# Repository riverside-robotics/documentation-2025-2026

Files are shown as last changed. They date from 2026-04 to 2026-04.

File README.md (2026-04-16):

# Spinlayden 2.0 — Riverside Robotics Documentation

**Team Meltdown** | Riverside High School | AWT RoboBots 2025-2026

**Documentation Due:** April 18, 2026 (11:59 PM)
**Competition:** April 25, 2026

---

## Repository Structure

| File | Description |
|---|---|
| `main.md` | Main documentation file — all sections for the AWT submission |
| `meetingNotes.md` | Meeting minutes from September 2025 to April 2026 |
| `aboutStudents.md` | Team member biographies (submit yours here) |
| `todo.md` | Tracks what still needs to be done and what has been completed |
| `interviewPrep.md` | Interview preparation for the 15-minute judge interview |
| `designTeamRequest.md` | Checklist of items needed from the design/CAD team |
| `rubricCompliance.md` | Tracks how far we are with AWT rubric compliance |
| `Images/` | Folder for all photos, CAD renders, and diagrams |

---

## How to Contribute

### Submitting Your Bio

Add your biography to `aboutStudents.md` — **do not** put it directly in `main.md`. Tom will move it into the main doc.

### Uploading Images

Upload images to the `Images/` folder and let Tom know which ones to use and where they should go in the doc.

### Helping with the Documentation

Check `todo.md` for outstanding tasks. When you complete one, mark it as done by wrapping the line with `~~` (strikethrough). See existing completed items in `todo.md` for examples.

### Submitting Design Content

If you are on the design or CAD team, check `designTeamRequest.md` for the specific items needed (CAD renders, engineering drawings, design descriptions). Send completed items to Tom or drop them in Google Classroom.

---

## Quick Links

- **Main Doc:** [main.md](main.md)
- **Meeting Notes:** [meetingNotes.md](meetingNotes.md)
- **TODO List:** [todo.md](todo.md)
- **Interview Prep:** [interviewPrep.md](interviewPrep.md)
- **Design Team Request:** [designTeamRequest.md](designTeamRequest.md)
- **Rubric Compliance:** [rubricCompliance.md](rubricCompliance.md)

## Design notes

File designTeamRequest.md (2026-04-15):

# Design Team — Content Needed for Documentation

**From:** Tom (Documentation)
**To:** Adam, Ayden, Jayden, Adam P., and the rest of the design team
**Deadline:** ASAP — documentation is due April 18 at 11:59 PM, competition is April 25

---

## What This Is

The **Design** section of our main documentation still has placeholder content. I need the design team to provide the following items so I can fill it in. Below is exactly what's needed, with examples from last year's Spinlayden doc and the Blue Streak of Death example doc for reference.

---

## Item 1: Previous Bot Write-Up

**What I need:** A short write-up about Spinlayden 1.0 (2025) similar to how last year's doc covered Mass & Acceleration.

**Format (follow this structure):**

> **Spinlayden 1.0 — 2025**
>
> [1-2 sentence description of the bot and what it taught us]
>
> [Photo/render of Spinlayden 1.0]
>
> **Strengths:**
> - [bullet points]
>
> **Weaknesses:**
> - [bullet points]

**What I already have (you can confirm, edit, or add to these):**

Strengths I've identified from the docs:
- Hexagonal full-body spinner concept worked
- Meltybrain drive system allowed spin + translate simultaneously
- Double-sided design — operates when flipped
- 6061 aluminum chassis was strong and lightweight
- A516 carbon steel blades held up to impact

Weaknesses I've identified:
- Weight reduction holes weakened the walls
- Components were too close to the outer walls
- Claw-style blades didn't puncture well
- No housing for the Raspberry Pi
- Python software had input lag
- Bluetooth controller dropped connection
- Counterweight system was overly complex

**What I still need from you:**
- [ ] A photo or CAD render of Spinlayden 1.0 (the old bot)
- [ ] Confirm or correct the strengths/weaknesses above
- [ ] A 1-2 sentence summary of what Spinlayden 1.0 taught us as a team

---

## Item 2: Design Section Introduction

**What I need:** A short paragraph (3-5 sentences) introducing the Design section. This goes at the very top, before Influences.

**It should cover:**
- What the design philosophy is for Spinlayden 2.0
- Why we chose to iterate on the existing design rather than start fresh
- A brief mention of the key improvements this year

**Example from last year's doc:**
> *"Spinlayden's design is driven by the goal of delivering maximum damage while maintaining agility and resilience. The 14" x 12" hexagonal chassis, crafted from 1/8" 6061 aluminum with vent-like cutouts, optimizes weight and heat dissipation..."*

**What I still need from you:**
- [ ] A short intro paragraph for the Design section (or bullet points and I'll write it up)

---

## Item 3: 2026 Design Description

**What I need:** Content for the `**2026 Design:**` line near the top of the doc (currently empty, line 39).

**It should be:** 1-3 sentences summarizing this year's design direction.

**Example:** "For 2026, Spinlayden has been redesigned from the ground up while keeping the proven hexagonal meltybrain full-body spinner concept. Key improvements include redesigned weight reduction, a dedicated Raspberry Pi housing, sharper spike-style blades, and a complete software rewrite in C#."

**What I still need from you:**
- [ ] Confirm the example above works, or write your own version

---

## Item 4: CAD Renders / Photos

**What I need:** Images for the documentation. The example doc (Blue Streak of Death) had multiple CAD views and photos throughout.

**Specifically needed:**
- [ ] CAD render of Spinlayden 2.0 — isometric/3D view (like last year's doc page 51)
- [ ] CAD render — top-down view showing blade layout
- [ ] CAD render — side view showing wall height and weight reduction
- [ ] Photo of the old Spinlayden 1.0 bot (for the Previous Bot section)
- [ ] Any in-progress build photos (assembly, waterjet cutting, CNC milling, 3D printing)
- [ ] Exploded view of the assembly if available in Fusion 360

---

## Item 5: Engineering Drawing Set

**What I need:** Dimensioned engineering drawings from Fusion 360.

**The example doc (pages 92-105) included drawings for:**
- Overall assembly with key dimensions
- Individual fabricated parts (chassis plates, walls, blades)
- Motor/component specs and mounting locations

**What I still need from you:**
- [ ] Export dimensioned drawings from Fusion 360 (PDF or image format)
- [ ] Include: overall dimensions, bolt hole patterns, weight reduction geometry, blade dimensions

---

## Summary Checklist

| # | Item | Who | Done? |
|---|---|-----|---|
| 1 | Previous Bot write-up (confirm strengths/weaknesses + photo) | Adam, Design team | [ ] |
| 2 | Design section intro paragraph | Adam, Design team | [ ] |
| 3 | 2026 Design description (1-3 sentences) | Adam, Design team | [ ] |
| 4 | CAD renders (isometric, top-down, side, exploded) | Ayden, Adam P., Jayden | [ ] |
| 5 | Photo of Spinlayden 1.0 | Anyone who has one | [ ] |
| 6 | In-progress build photos | Everyone | [ ] |
| 7 | Engineering drawings from Fusion 360 | CAD team | [ ] |

Please send completed items to Tom or drop them in the Google Classroom. Even partial info is helpful — I can write it up from bullet points.

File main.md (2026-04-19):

# Spinlayden 2.0

## Team Meltdown — Riverside Robotics

**Riverside High School** · 585 Riverside Dr, Painesville, OH 44077

**AWT Regional RoboBots Competition — 2025–2026 Season**

### Team Members

| | | |
|---|---|---|
| Adam Pakeltis | Alexander Holmes | Ayden Moore |
| Benjamin Mackey | Daniel George | Dustin Hance |
| Jason Kellhofer | Jayden Craig | Kasey Kurzinger |
| Kaydan Kerr | Lukas Dauksa | Mher Poghosyan |
| Robert Rateno | Richard Rowland | Sultan Kazeem |
| Tom Kramer | Vincent Riha | Xayden Minch |
| Yash Jain | | |

**Advisors:** Jack Carbone, Adam Carbone &nbsp;·&nbsp; **Industry Advisor:** J.T. Mackey (Monode Marking Products, Inc.)

**Sponsors:** Monode Marking Products, Inc. &nbsp;·&nbsp; Show Studio LLC &nbsp;·&nbsp; Arc Technology LLC

---

## Meet the Robotics Team

**Overview:** Since 2022, Riverside High School had been without a robotics team. Former Class of 2023 students, Adam and Jack Carbone, took the opportunity to establish one. In just four months, from January to April, not only was a team formed, but Riverside Robotics also learned to design and manufacture its first robot in years, Spinlayden. This year, the high school roster has grown to 19 students on Team Meltdown, with two additional JuniorBots middle-school teams also running under advisors Jack and Adam Carbone.

**2026 Design:** Spinlayden 2.0 is the team's second-generation 15-pound hexagonal meltybrain full-body spinner, built around a 6061 aluminum chassis with six 1/2" carbon steel hex bolts as impact weapons and driven by dual BaneBots P61 gearboxes at 645.6 RPM (≈26.9 mph tip speed, ~78 J per rotation). This season's redesign focuses on the failure points identified from Spinlayden 1.0 — reinforcing the chassis walls, redesigning the gearbox and bearing mounts for easier serviceability and better belt tension, and moving the meltybrain control software from Python to C# on a Raspberry Pi for tighter simultaneous-rotation-and-translation drive control.

---

## Table of Contents

- [About Riverside](#about-riverside)
- [Our Partners](#our-partners)
- [Team Biographies](#team-biographies)
- [Mentor / Advisor Biographies](#mentor--advisor-biographies)
- [Acknowledgements](#acknowledgements)
- [Design](#design)
  - [Influences](#influences)
  - [Key Stats of the Bot](#key-stats-of-the-bot)
  - [What Was Changed from the Previous Design](#what-was-changed-from-the-previous-design)
- [Project Overview](#project-overview)
  - [General Information](#general-information)
  - [Sponsors](#sponsors)
  - [Advisors](#advisors)
  - [Manufacturing](#manufacturing)
  - [Bot Description](#bot-description)
  - [Objective](#objective)
  - [Team Members](#team-members)
  - [Deliverables](#deliverables)
  - [Key Milestones](#key-milestones)
  - [Constraints / Risks / Dependables](#constraints--risks--dependables)
- [Team Meltdown - Tasks Distribution](#team-meltdown---tasks-distribution)
  - [Project Assignments](#project-assignments)
- [Team Procedures](#team-procedures)
  - [Material Management](#material-management)
  - [Our Component Philosophy](#our-component-philosophy)
  - [Fabrication](#fabrication)
  - [Inventory](#inventory)
- [Design Process](#design-process)
  - [Research](#research)
  - [Strategy](#strategy)
  - [Analysis and Conceptualization](#analysis-and-conceptualization)
  - [Design Motivation](#design-motivation)
  - [Research Methods](#research-methods)
  - [Risk Analysis](#risk-analysis)
  - [Structural Analysis](#structural-analysis)
  - [Weapon System Details](#weapon-system-details)
  - [Drive System Details](#drive-system-details)
  - [Power System Details](#power-system-details)
  - [Wiring Schematic](#wiring-schematic)
  - [Testing Results](#testing-results)
- [That's a Wrap!](#thats-a-wrap)

---

## About Riverside

Riverside High School is a public high school located in Painesville, Ohio, serving the communities of Painesville Township, Concord, Leroy, and Grand River in Lake County. Part of Riverside Local Schools, the district holds true to its mission of providing A Pathway to Excellence by immersing students in educational opportunities that prepare them for success in college, careers, and beyond. Riverside strives to develop well-rounded individuals who are proactive in their communities and equipped with the skills necessary to thrive in a rapidly evolving world.

Connecting with this commitment to excellence, Riverside Robotics encourages hands-on learning, creative problem-solving, and independent thinking—qualities that are essential both in the arena and in life. Advised by Jack Carbone and Adam Carbone, both Class of 2023 alumni who returned to volunteer their time, Riverside Robotics aims to uphold the school's mission through the range of experiences in which students participate.

Riverside Robotics has a rich history dating back to the 2010s, competing in the AWT RoboBots program at Lakeland Community College—Ohio's largest regional combat robotics competition and a National Robotics League sanctioned event. In 2021, the team earned third place with Pfizer and Moderna, a pair of weaponless wedge bots designed around a strategy of control, domination, and superior torque. The following year, the team fielded Mass and Acceleration, a non-uniform dual-bot entry featuring both spinner and wedge designs, demonstrating the program's continued commitment to innovation and experimentation.

Following a brief hiatus, Riverside Robotics was revived in 2025 when alumni advisors Jack and Adam Carbone returned to reestablish the program. In just four months, from January to April, not only was a team of eight students formed, but Riverside Robotics also learned to design and manufacture its first robot in years: Spinlayden, a 15-pound meltybrain full-body spinner. Although competition results were modest, the inaugural revival season proved to be an overwhelming success—a year defined by excitement, growth, and invaluable learning experiences for every member of the new team.

At Riverside, the robotics program has achieved significant success beyond the arena. Alumni of the program have gone on to pursue degrees in mechanical engineering, software engineering, and other engineering disciplines at colleges and universities. Through robotics, students gain exposure to real-world manufacturing skills, CAD design, electronics, and the iterative process of engineering—experiences that have shaped their academic and professional futures.

The 2025-2026 season marks a historic expansion for Riverside Robotics. The high school competition team, Team Meltdown, has grown to 19 students fielding Spinlayden 2.0, an evolved iteration of the meltybrain spinner. Alongside the high school team, the JuniorBots program was revived from scratch this year, with two middle school teams—Team Pickle Pirates competing with The Pickler, a horizontal spinner, and Team Tornadoes bringing The Tempest to the arena. Each JuniorBots team boasts 15 to 20 students, a testament to the growing enthusiasm for robotics throughout the district.

The goal of Riverside Robotics is not only to compete at the highest level, but also to spread the joy of engineering and instill valuable skills applicable in the real world. Through teamwork and collaboration, students learn how to support each other, solve complex problems under pressure, and transform ideas into reality. This aligns closely with Riverside's mission of providing a pathway to excellence, and embodies a spirit of innovation, leadership, and perseverance.

---

## Our Partners

Riverside Robotics is proud to partner with local businesses and organizations that share our commitment to inspiring the next generation of engineers and innovators. Their generous support makes our program possible.

### Monode Marking Products, Inc.

Monode Marking Products, Inc. is an American manufacturer specializing in permanent part-marking and traceability solutions for industrial applications. As a third-generation, family-owned business celebrating 75 years in the marking industry, Monode has built its reputation on delivering practical, reliable solutions that perform in real-world environments.

Headquartered in Mentor, Ohio, Monode maintains a strong focus on North America while serving customers worldwide across industries including the Department of Defense, aerospace, automotive, medical, and food and drug sectors. The company provides a full range of marking technologies, including laser, dot peen, electro-chemical etching, steel stamp, and high precision die systems, along with integrated machine vision solutions.

What sets Monode apart is its focus on the complete system—not just the marking device. By combining marking hardware, proprietary software, and system integration with existing customer workflows, Monode delivers solutions that are reliable, scalable, and built for long-term use. Their team works closely with customers to design, implement, and support turnkey systems that meet production demands while ensuring compliance with requirements such as DoD Item Unique Identification (IUID).

Beyond equipment, Monode provides consulting, system design, installation, training, and ongoing support to ensure customers achieve consistent performance and long-term value. This practical, full-system approach has made Monode a trusted partner for organizations that depend on accurate, repeatable, and fully traceable marking solutions.

If you would like to learn more about Monode Marking Products, we encourage you to visit: https://www.monode.com/

### Arc Technology LLC

Arc Technology LLC is an electronics and engineering company founded in 2025 by Riverside Robotics advisor Adam Carbone. Based in Cleveland, Ohio, Arc Technology designs, develops, and delivers innovative products across engineering, electronics, and emerging technologies. Their flagship product, the FPV Sim Link, is a patent-pending device that converts HDMI to 5.8GHz RF for FPV drone simulator training. Arc Technology provides financial support to help sustain and grow the robotics program.

### Show Studio LLC

Show Studio LLC is a software company founded in 2025 by Riverside Robotics advisor Jack Carbone. Inspired by Riverside High School's own Riverside Regiment marching band, Show Studio develops marching band drill design software delivered as a Software-as-a-Service platform. The software features 3D visualization and coordinate generation tools to help band directors and designers bring their creative visions to life. Currently in beta, Show Studio provides Riverside Robotics with funding, 3D printers, portable CNC mills, and other materials essential for robot fabrication.

Through the combined support of our partners, Riverside Robotics is able to offer students access to professional-grade resources, real-world manufacturing experience, and mentorship that prepares them for careers in engineering and technology.

---

## Team Biographies

**Adam Pakeltis:** This hardworking senior is thrilled to join Team Meltdown for his very first year. Alongside robotics, Adam has played football and is an active member of the National Honor Society. Outside of the cage, this first-time competitor stays incredibly busy. He volunteers for both NHS and the Lake Metroparks, works weekends at Hellriegel's Inn, lifts weights, fishes, and enjoys working outside. When he isn't building plastic model kits or designing projects in Fusion 360, he loves hanging out with his girlfriend and watching "Deal or No Deal" with his family. This well-rounded student is more than ready to bring his diverse skills to the team and experience his first competition.

**Alexander Holmes:** Returning for his second year, this sharp junior brings a strategic mindset to Team Meltdown and leads the team's marketing operations. Along with robotics, he is actively involved in Accounting and Model UN. Outside of school, he enjoys reading, following Formula 1, and competing in fencing. With a full season of experience behind him, Alexander is well positioned to represent the team at competition.

**Ayden Moore:** This returning junior is back and ready to conquer the cage for his second competition. As the team's all-around helper, Ayden is actively involved in Robotics, Esports, and NTHS. Outside of school, he enjoys programming, exercising, watching TV, and playing video games. This versatile competitor is eager to take the wheel to drive a bot and watch it win.

**Benjamin Mackey:** This enthusiastic eighth grader is thrilled to step into the cage for his very first year. At 14 years old, Ben brings a positive attitude and a strong love for math to the team. Always happy to help and ready for a challenge, this cheerful rookie is excited to calculate the team's path to victory and gain valuable experience in his first competition.

**Daniel George:** This talented junior is stepping into the cage for his very first time. Daniel brings his skills to both the mechanical and documentation sides of the team. He is actively involved in robotics, Model UN, and marching band. Outside of school, he enjoys skiing and teaching others on the slopes, playing the saxophone, drawing, and conquering *Dark Souls*. This dedicated student is eager to dive into the competition and gain valuable experience this season.

**Dustin Hance:** Returning for his second year on the Riverside robotics team, this junior brings a strong passion for computers, networking, cybersecurity, and programming. On the software team, Dustin has been central to keeping Spinlayden 2.0's Raspberry Pi running — setting up the headless OS, managing dependencies, and pulling the team's latest code from GitHub throughout the season. In his free time, he enjoys playing video games and tinkering with his personal homelab. This tech-savvy competitor is ready for the season and committed to delivering reliable control software for Spinlayden 2.0.

**Jason Kellhofer:** This aspiring freshman steps into the arena for his first ever competition! Jason Kellhofer brings a dedicated mindset to the team, focusing on maintaining precise documentation and completing any tasks assigned to him. He consistently pushes himself academically by tackling a full schedule of honors classes, showcasing his drive for excellence. Outside the classroom, Jason likes to play wiffleball and diving into computer systems to expand his knowledge. This proactive competitor is eager to see how his and his team's skills combine to ensure a secured win this season.

**Jayden Craig:** This experienced sophomore returns to the arena for his second year with Team Meltdown. Coming in with a year of firsthand experience on the Spinlayden project, Jayden hits the ground running with a working knowledge of the design, and has contributed across mechanical design, CAD modeling, marketing, manufacturing, and assembly. His versatility makes him a reliable presence anywhere on the team. This returning competitor is eager to put his experience to work and help bring Spinlayden 2.0 across the finish line.

**Kasey Kurzinger:** This enthusiastic eighth grader steps into the arena for his very first competition! Kasey has jumped in headfirst as a first-year member, contributing to CAD design, documentation, manufacturing, and assembly alongside his teammates. His quick learning and willingness to take on any task have made him a valuable addition to the team. This eager rookie is ready to see how his hard work comes together in the arena.

**Kaydan Kerr:** This eager eighth grader steps into the cage for his very first competition! Kaydan came to Team Meltdown with a genuine interest in robotics and battle bots, and has channeled that enthusiasm into real contributions — overseeing design and specification decisions and jumping in wherever needed during assembly. With a sharp eye for how the robot should come together, he brings both curiosity and commitment to the team. This first-year competitor can't wait to see Spinlayden 2.0 in action.

**Lukas Dauksa:** This hardworking junior steps into the arena for his very first competition! Lukas brings hands-on energy to the team's electrical work, contributing to the spec and design process and pitching in during assembly to help keep the build moving forward. His willingness to get involved and learn on the fly has made him a reliable team member throughout the season. This first-year competitor is ready to see what the team has built take the stage.

**Mher Poghosyan:** This dedicated junior steps into the cage for his very first competition! Mher has contributed to both the documentation and mechanical sides of the team, bringing careful attention to detail to spec and design discussions while pitching in during assembly to move the build forward. His ability to bridge the gap between documentation and hands-on work has made him a versatile and dependable presence on the team. This first-year competitor is excited to see everything come together in the arena.

**Richard Rowland:** This energetic eighth grader steps into the arena for his very first competition! Richard has been fully hands-on all season, contributing to spec and design discussions and jumping in during assembly to help bring Spinlayden 2.0 to life. His willingness to learn, adapt, and take on whatever is needed has made him a dependable part of the team. This first-year competitor is ready to see what he and his teammates have worked so hard to build.

**Robert Rateno:** This returning sophomore is ready to hit the cage for their second competition. As the team's driver, they are prepared to take the wheel and steer the robot to victory. Alongside robotics, this student keeps the beat in the school's marching band. Outside of school, they enjoy playing the drums, 3D printing, and tinkering with RC vehicles. This experienced competitor is excited to show off their driving skills and dominate the competition.

**Sultan Kazeem:** This bright junior is stepping into the cage for his very first time. Bringing his skills to the mechanical team, Sultan is excited to win at competition. He is actively involved in Model UN, Academic Challenge, choir, and Investment Club. When not building robots, he enjoys bike riding. This hardworking student cannot wait to dominate.

**Tom Kramer:** This brilliant junior has traveled all the way from Germany to show the competition what he is made of! As a foreign exchange student at Riverside, Tom is more than ready to make his mark in robotics. On the team, he is the mastermind behind the screen, specializing in software and keeping the team's documentation in perfect order. Outside of prepping the robot for battle, this tech-savvy student spends his free time coding and learning everything he can about computers. This dedicated programmer is excited to show off his skills and help lead the team to victory.

**Vincent Riha:** This talented sophomore steps into the arena for his very first competition! Vincent brings software skills to the team, contributing to the spec and design process and pitching in during assembly to support the build. His technical background and hands-on approach have made him a valuable first-year addition to Team Meltdown. This newcomer is ready to put the team's work to the test in the arena.

**Xayden Minch:** This ambitious freshman is stepping into the arena for his very first competition! Xayden brings a versatile set of skills to the team, where he focuses on maintaining detailed documentation and tackling any miscellaneous tasks needed to keep the project moving forward. A dedicated member of the school band, he stays just as busy outside the classroom. Whether he is playing the flute, building computers from scratch, coding, or diving into video games, he is always exploring the world of technology. This proactive competitor is eager to contribute his technical talents and help the team achieve a successful season.

**Yash Jain:** This 15-year-old freshman brings Python programming skills and a strong interest in electrical work to the team, contributing across both the software and electrical subteams. Whether he is wiring the robot or pitching in on the codebase, Yash has been a consistent and enthusiastic presence throughout the season. This first-year competitor is excited to put his technical skills to work on Spinlayden 2.0.

## Mentor / Advisor Biographies

**Adam Carbone — Co-Advisor:** Adam Carbone is an electrical engineering student at Cleveland State University and an intern at NASA Glenn Research Center, where he has spent seven semesters contributing to lunar power application projects, progressing from Regenerative Fuel Cell systems to Fission Surface Power, and moving next into 3-phase motor controller design for cryogenic cooling systems on lunar and Martian reactors. He is the founder of Arc Technology, a hardware startup with a product currently launching on Kickstarter, and a co-sponsor of the AWT RoboBots program alongside his brother and fellow advisor, Jack Carbone. As an advisor for AWT RoboBots, Adam contributes across CAD and mechanical design in Autodesk Fusion, custom PCB design and soldering, C# software development, and electrical systems including component selection and device communications. He is committed to giving students the kind of hands-on experience, direct mentorship, and real engineering exposure that sets them up to build, problem-solve, and grow well beyond the classroom. Adam and Jack revived the AWT RoboBots program in 2025 after a multi-year hiatus, growing it from a small remaining group of dedicated students into a thriving organization spanning both high school and middle school teams. For Adam, the program is an investment in the next generation of engineers, and a chance to give students the support, resources, and guidance to do something real.

**Jack Carbone — Lead Advisor:** Jack Carbone is a software developer and the founder and CEO of Show Studio LLC. As Lead Advisor of Riverside Robotics, Jack oversees all club operations and contributes across software development in C# and .NET, CAD design, and hands-on bot manufacturing. Alongside his brother and co-advisor, Adam Carbone, he revived the Riverside Robotics program in 2025 after a multi-year hiatus, growing it from a small group of students into a thriving organization spanning both high school and middle school teams. For Jack, Riverside Robotics is an investment in the future of engineering in software and hardware and, by extension, the future of humanity. He is committed to giving students the hands-on experience, financial backing, and guidance he never had access to, preparing the next generation of engineers to lead, innovate, and shape the world across every discipline the field has to offer.

**J.T. Mackey — Industry Advisor:** J.T. Mackey is a leader at Monode Marking Products, Inc., where he focuses on delivering practical, real-world solutions for industrial marking and traceability. A recognized subject matter expert, he has co-authored ANSI, ISO and military standards and currently serves as Chair of MH10.8.2, helping guide industry standards across multiple sectors. J.T. is also a patent holder and works closely with customers to ensure marking systems integrate effectively into production environments with a focus on reliability and long-term performance. Outside of work, he is deeply committed to his family—his wife Jenn and their children, Ben and Abby—and to his community. He is proud to support Monode's partnership with the Riverside robotics program, where his son Ben is a team member, helping inspire the next generation of engineers.

## Acknowledgements

Team Meltdown would like to thank everyone who has contributed to making the Spinlayden 2.0 project possible this season. The success of our team is built on the generosity, expertise, and encouragement of the people and organizations around us.

First and foremost, we would like to thank our industry sponsor, **Monode Marking Products, Inc.**, and its President, **J.T. Mackey**, for providing Riverside Robotics with shop access for machining, mentorship from professional engineers, and funding for materials. Monode's willingness to open their facility to our team and share their manufacturing expertise has been instrumental in bringing Spinlayden from a CAD model to a competition-ready robot. J.T.'s guidance as our Industry Advisor has given our students invaluable exposure to real-world engineering practices.

We would also like to thank **Arc Technology LLC**, founded by our advisor **Adam Carbone**, and **Show Studio LLC**, founded by our advisor **Jack Carbone**, for their financial support and material contributions to the program. Show Studio's donation of 3D printers, portable CNC mills, and other fabrication equipment has given our team access to manufacturing capabilities that would otherwise be out of reach for a high school program. Arc Technology's funding has helped sustain and grow the robotics program during this critical expansion year.

A special thank you to our advisors, **Jack Carbone** and **Adam Carbone**, both Class of 2023 alumni who returned to Riverside to rebuild the robotics program from the ground up. Their dedication to this team goes far beyond what is expected — from organizing meetings and coordinating with sponsors to mentoring students through every stage of the design, manufacturing, and documentation process. Without their leadership, Riverside Robotics would not exist in its current form.

We are grateful to **Riverside High School** for purchasing parts and materials for our robot and for providing the space, time, and institutional support needed to run a competitive robotics program. The school's commitment to hands-on STEM education has made it possible for our students to gain skills in engineering, manufacturing, and project management that will serve them well beyond the arena.

We would like to thank **Case Western Reserve University's think[box]** makerspace for providing access to their OMAX 5555 waterjet cutter. The precision and capability of their equipment allowed us to fabricate our hexagonal chassis plates to exact specifications — a critical step in our manufacturing process that would not have been possible without their facility.

Thank you to the **Alliance for Working Together (AWT)** for organizing the Regional RoboBots Competition. AWT's commitment to fostering the next generation of skilled manufacturing professionals gives programs like ours a platform to learn, compete, and grow.

Finally, we would like to extend our gratitude to the **parents, families, and community members** of Riverside Robotics. Your support — whether through transportation, encouragement, patience during late build sessions, or simply believing in what your students are building — makes all of this possible. Robotics is a team effort that extends well beyond the students in the room, and we are thankful for every person who has cheered us on this season.

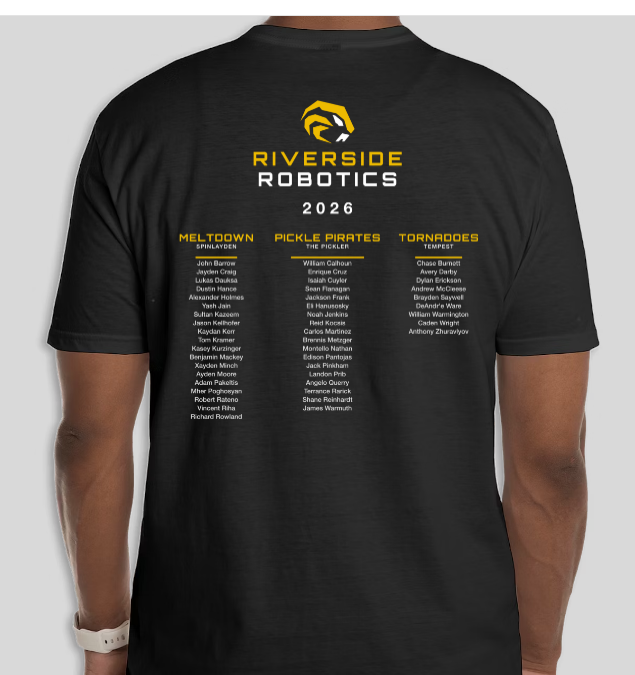
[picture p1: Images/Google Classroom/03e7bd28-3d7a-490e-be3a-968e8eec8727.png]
2026 Riverside Robotics team shirt listing every member of Team Meltdown (Spinlayden), Team Pickle Pirates (The Pickler), and Team Tornadoes (Tempest)


*The 2026 Riverside Robotics team shirt — listing every member across Team Meltdown (Spinlayden), Team Pickle Pirates (The Pickler), and Team Tornadoes (Tempest).*

---

## Design

The Design section documents how Team Meltdown arrived at Spinlayden 2.0, starting from the lessons learned on Spinlayden 1.0 and the broader survey of meltybrain full-body spinners covered in the Influences section above. Our overall design philosophy this season was *iterate, don't reinvent*: the 1.0 chassis proved the hexagonal meltybrain concept was competition-viable, so rather than discard that work we systematically identified the points where 1.0 underperformed — blade retention, weapon energy, motor stall margin, control-loop stability, and serviceability — and addressed each one in 2.0.

The 2.0 design is also built around a core combat strategy: maintain distance from opponents while the chassis ramps up to full weapon speed, then engage once the full kinetic energy of the spin is available. Because Spinlayden is a full-body spinner, the chassis itself is the weapon — every impact bolt around the perimeter becomes a strike surface once the robot reaches operational RPM. This strategy places significant demand on the driver, who must fluidly transition between **wheel mode** (pure translational driving for positioning and evasion) and **melty mode** (simultaneous rotation and translation for engagement), and maintain awareness of the robot's readiness at all times.

Primary design decisions for Spinlayden 2.0 were led by students **Adam Pakeltis** and **Robert "Robby" Rateno**, with advisor **Adam Carbone** reviewing and approving each major design choice. This arrangement allowed the student designers to drive the creative and technical direction of the project while ensuring every decision was validated against engineering best practices and competition requirements before being committed to manufacturing.

The subsections that follow describe the previous bot in detail, the concrete strengths we preserved and weaknesses we corrected, and the resulting 2026 design with its key stats, CAD renders, and dimensioned engineering drawings.

**Previous Bot: Spinlayden 1.0 — 2024 - 2025 Season**

Spinlayden 1.0 was Riverside Robotics' first meltybrain full-body spinner, designed and built by an eight-member team during the 2024–2025 season under advisors Jack Carbone and Adam Carbone, with industry advisor Jeffrey Clarke. The robot featured a 14" × 12" hexagonal chassis machined from 1/8" 6061-T6 aluminum with vent-like weight reduction cutouts. Six A516 Grade 70 carbon steel blades, totaling 38 oz, were mounted around the perimeter. Powered by REV UltraPlanetary gearmotors and controlled by a Raspberry Pi 4B running Python-based meltybrain algorithms, the bot achieved a rotational speed of 645.6 RPM and delivered approximately 78 joules of kinetic energy per rotation within the 15 lb weight class.

The double-sided design allowed the robot to operate when inverted, eliminating the need for a self-righting mechanism. Spinlayden 1.0 proved the viability of the hexagonal meltybrain concept for the AWT competition and provided returning team members with direct experience in full-body spinner design, fabrication, and competition strategy.

*Figure 1: Spinlayden 1.0 — Isometric CAD Render. CAD: Design Team (2024–2025 roster archive).*

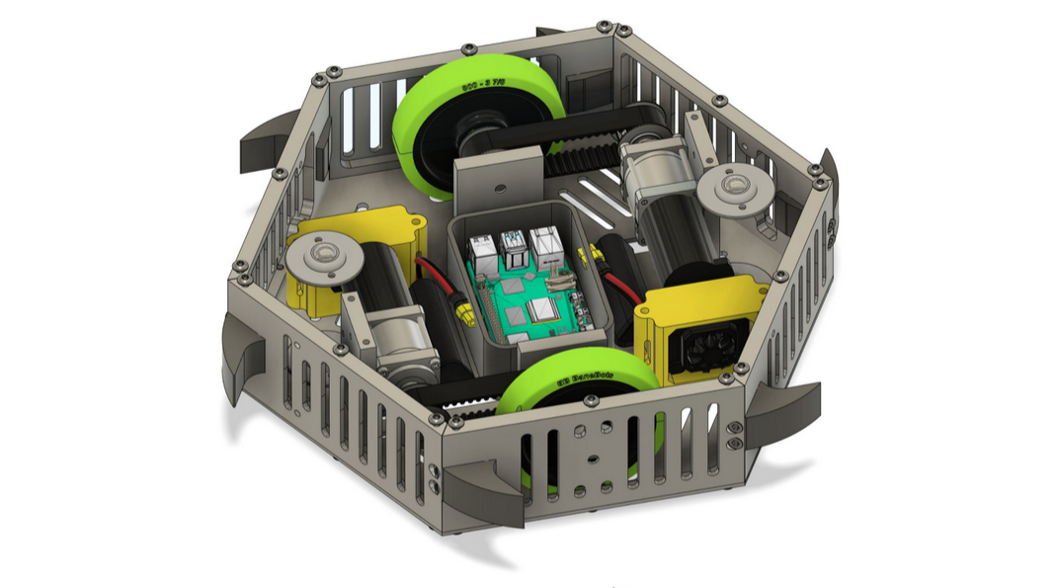
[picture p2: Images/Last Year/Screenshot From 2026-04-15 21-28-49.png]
Spinlayden 1.0 — Isometric CAD Render


*Figure 2: Spinlayden 1.0 — Top-Down CAD Render showing hexagonal chassis, six perimeter blades, dual drive wheels, and central Raspberry Pi housing. CAD: Design Team (2024–2025 archive).*

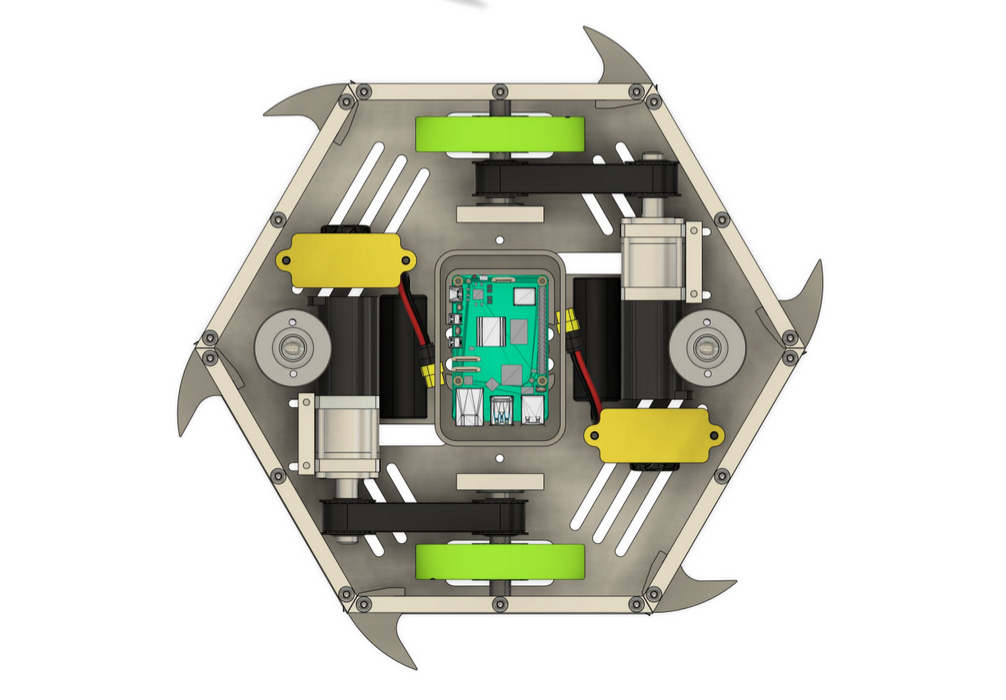
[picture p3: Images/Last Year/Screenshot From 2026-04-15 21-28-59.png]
Spinlayden 1.0 — Top-Down CAD Render


*Figure 3: Spinlayden 1.0 — Physical bot following the 2025 competition, featuring the Riverside Robotics logo painted on the chassis. Photo: Riverside Robotics archive (2024–2025 season).*

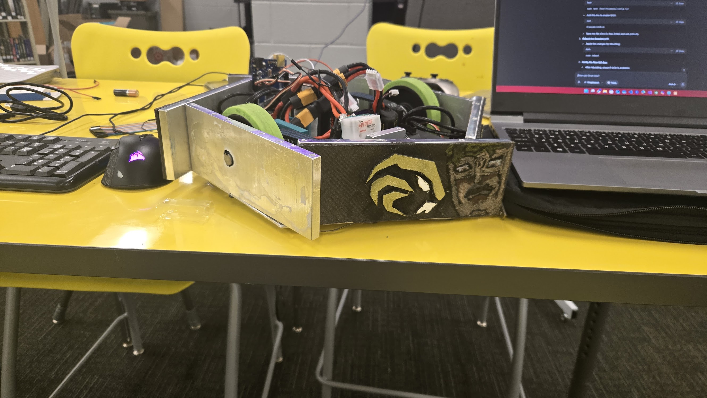
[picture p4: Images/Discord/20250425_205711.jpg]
Spinlayden 1.0 physical bot with Riverside Robotics logo


**Strengths:**
- Hexagonal full-body spinner concept validated for competition
- Meltybrain drive system enabling simultaneous rotation and translation
- Double-sided chassis design for invertibility
- 6061-T6 aluminum chassis providing a strong, lightweight structure
- A516 Grade 70 carbon steel blades delivering high impact toughness

**Weaknesses:**
- Through-hole weight reduction cutouts compromised chassis wall integrity
- Internal components positioned too close to outer walls, vulnerable to impact
- Claw-style blade tip geometry spread force over too wide an area, reducing penetration
- No dedicated housing for the Raspberry Pi controller
- Python control software introduced noticeable input latency
- Bluetooth Xbox controller caused frequent connection drops with the Pi
- Central counterweight system added unnecessary complexity and weight

### Influences

This year's Spinlayden 2.0 is directly inspired by last year's Spinlayden, Riverside Robotics' first meltybrain full-body spinner. The original bot proved the viability of the hexagonal meltybrain concept and gave us a strong foundation to build on. By analyzing what worked well and what fell short during the 2025 season, we identified specific areas to carry forward and specific problems to solve in this year's redesign.

#### Positive and Negative Aspects of Spinlayden 1.0

**Table 1:** Positive and Negative Aspects of Spinlayden 1.0

| Positive | Negative |
|---|---|
| Hexagonal full-body spinner concept | Weight reduction holes weakened structural integrity |
| Meltybrain drive system (spin + translate) | Internal components too close to walls, vulnerable to impact damage |
| Double-sided design (operates when flipped) | Claw-style blades lacked puncture effectiveness |
| 6061 aluminum chassis (strong, lightweight) | No dedicated housing for the Raspberry Pi |
| A516 carbon steel blades (impact-tough) | Software written in Python introduced noticeable input lag |
| Reusable parts and design knowledge for returning members | Bluetooth controller caused frequent connectivity issues with the Pi |
| Compact hexagonal shape fits well in the arena | Counterweight system added unnecessary complexity and weight |

#### Negative Aspects — Problems and Solutions

**Table 2:** Problems Identified in Spinlayden 1.0 and Solutions Implemented in 2.0

| # | Negative | Problem | Solution |
|---|---|---|---|
| 1 | Weight reduction holes | The through-holes used for weight reduction in Spinlayden 1.0 compromised the structural integrity of the chassis walls, creating weak points that could fail under repeated impacts. | Redesigned weight reduction to go only part of the way through the walls, preserving structural strength without sacrificing weight savings. No more through-holes. |
| 2 | Components too close to walls | Internal electronics and drive components were mounted near the outer walls, making them vulnerable to damage when the chassis absorbed hits during combat. | Pushed all components away from the walls toward the center of the bot, creating a buffer zone between the impact surface and sensitive internals. |
| 3 | Claw-style blades | The original claw-shaped blade weapons spread impact force across a wider area, reducing penetration and damage output against armored opponents. | Replaced the machined blade system entirely with 1/2" carbon steel hex bolts threaded through the chassis walls, concentrating force through the bolt tip and shank for improved impact performance. |
| 4 | No Raspberry Pi housing | The Pi was mounted without a dedicated enclosure, leaving it exposed to vibration, debris, and potential impact damage — especially critical since the Pi now handles all onboard processing. | Designed and manufactured a dedicated housing for the Raspberry Pi, protecting the brain of the bot from physical damage during combat. |
| 5 | Python software lag | The original Python control script introduced noticeable latency in processing controller inputs and gyroscope data, reducing responsiveness during matches. | Rewrote the entire software stack in C#, significantly reducing input lag and improving real-time responsiveness of the meltybrain control system. |
| 6 | Bluetooth controller issues | The first-party Xbox controller connected via Bluetooth frequently dropped connection with the Raspberry Pi, causing loss of control during critical moments. | Switched to a traditional analog RC car controller with a dedicated receiver, eliminating Bluetooth reliability issues entirely. |
| 7 | Counterweight complexity | The central counterweight system from the original design added moving parts, weight, and manufacturing complexity without proportional performance benefit. | Removed the counterweight system entirely, reclaiming weight budget for other components and reducing points of failure. |

### What Was Changed from the Previous Design

- Partial-depth pockets machined into the chassis walls replace the full through-holes, preserving structural integrity while achieving weight savings
- Redesigned weight reduction geometry for improved stress distribution
- Internal components repositioned toward the chassis center to reduce vulnerability to impact damage
- Dedicated 3D-printed housing for the Raspberry Pi onboard controller
- Replaced machined blade-style weapons with 1/2" carbon steel hex bolts threaded through the chassis walls, concentrating impact force through the bolt tip and shank

---

## Project Overview

### General Information

**Table 3:** General Project Information

| Field | Detail |
|---|---|
| Name | Spinlayden |
| Project Number | 5 |
| Start of Session | 9/24/2025 |
| Date of Completion | 4/25/2026 (Documentation due 4/18/2026 at 11:59 PM) |

### Sponsors

Monode Marking Products, Inc., Show Studio LLC, Arc Technology LLC

### Advisors

Jack Carbone, Adam Carbone

### Manufacturing

Spinlayden 2.0 was fabricated using three complementary processes across two primary facilities. **Waterjet cutting** of the 1/8" 6061-T6 aluminum hexagonal top and bottom plates was performed on an OMAX 5555 at **Case Western Reserve University's think[box]** makerspace in Cleveland. **CNC milling** of the 3/8" 6061-T6 aluminum perimeter walls and other precision machined parts (bearing mount, gearbox mount) was handled at sponsor **Monode Marking Products** in Mentor, Ohio, under industry advisor J.T. Mackey. **FDM 3D printing** in PLA was done in-house at Riverside High School on printers donated by Show Studio LLC for internal brackets (battery, Pi/IMU), prototype iterations, and the placeholder walls used to validate wiring in parallel with off-site machining. The weapons are six 1/2" zinc-plated carbon steel hex bolts (Everbilt SKU 800980) threaded directly through the chassis walls — one per face — rather than custom-machined blades.

The waterjet session at think[box] ran approximately four hours total. The first hour was spent converting the DXF part files exported from Fusion 360 into the OMAX-compatible ORD format and setting up the job; the remaining three hours were used for cutting and loading, with other makerspace users slotted in between our runs. The OMAX itself ran for roughly one hour of machine time across two nests of two hexagonal plates each, yielding four plates total. No parts needed to be remade. One post-processing adjustment was required: the team manually enlarged several bolt holes after cutting to compensate for the cut face direction selected during waterjet setup. With all major parts fabricated in a single session and no rework required, the team moved efficiently from raw stock to assembled chassis. Detailed step-by-step fabrication procedures, run times, costs, and material justifications are documented in the *Team Procedures → Fabrication* section below.

### Bot Description

Spinlayden is a 15-pound combat robot designed to compete in the Regional RoboBots Contest organized by the Alliance for Working Together (AWT). Spinlayden enters its second design iteration (V2) this year; the focus is not to redesign the robot from scratch, but to analyze failure points from the previous season and address areas where the team ran out of development time. With a significantly larger team this year, Riverside Robotics aims to leverage this expanded roster to compete at the highest level in the AWT competition.

The High School Robotics Club is also an opportunity for Riverside Students to learn about manufacturing, engineering, teamwork, design, software, and documentation used in the engineering process.

### Objective

**Table 4:** Project Objectives, Metrics, and Goals

| Objective | Metric | Project Goal |
|---|---|---|
| Software | Control software that manages both rotational weapon operation and translational movement. | Developing a C# program that computes the translational vectors required for simultaneous rotation and translation. |
| Robustness | Withstanding impact damage from opposing robots and recovering from inversion during combat. | Maintaining operational capability and protecting the onboard control system (Raspberry Pi) under all combat conditions. |
| Offensive Output | Kinetic energy delivered per impact and tip speed at full operational RPM. | Delivering approximately 78 J of impact energy per rotation at 645.6 RPM (~26.9 mph tip speed) through the six 1/2" carbon steel hex-bolt impact weapons. |

### Team Members

- Adam Pakeltis
- Alexander Holmes
- Ayden Moore
- Benjamin Mackey
- Daniel George
- Dustin Hance
- Jason Kellhofer
- Jayden Craig
- Kasey Kurzinger
- Kaydan Kerr
- Lukas Dauksa
- Mher Poghosyan
- Robert Rateno
- Richard Rowland
- Sultan Kazeem
- Tom Kramer
- Vincent Riha
- Xayden Minch
- Yash Jain

### Deliverables

- [x] Company sponsor information *(see Our Partners)*
- [x] Statement of robot design intent *(see Design and Bot Description)*
- [x] Robot design specification and assembly *(see CAD Models, Engineering Drawing Set, and Fabrication → Assembly Process)*
- [x] Research and robot design ideas *(see Influences and Design Process → Research, Analysis and Conceptualization)*
- [x] Manufacturing procedure of robot design *(see Team Procedures → Fabrication)*
- [x] Quality control specifications and testing *(see Design Process → Testing Results)*
- [x] Possible robot design changes *(see Influences → What Was Changed and Design Process → Refinement)*

### Key Milestones

**Table 5:** Key Project Milestones and Target Dates

| Milestone | Target Date |
|---|---|
| Introduction | Sep 24 - Oct 8 |
| Design | Oct 9 - Dec 7 |
| Build | Jan 5 - Mar 17 |
| Prepare | Mar 18 - Apr 24 |
| Documentation Due | Apr 18 (11:59 PM) |
| Battle | Apr 25 |

### Constraints / Risks / Dependables

Since Riverside Robotics has previously designed, manufactured, and assembled a robot of Spinlayden's configuration, iterating on the existing platform does not present significant design challenges. Manufacturing access for the 2025–2026 season is secured through two primary partners: **Monode Marking Products** for CNC milling of the 6061-T6 aluminum perimeter walls, bearing mount, and gearbox mount, and **Case Western Reserve University's think[box]** for waterjet cutting of the hexagonal top and bottom plates on an OMAX 5555. Internal components are 3D printed in-house on printers donated by Show Studio LLC. The remaining project dependencies are the final integration and full-speed testing window (April 14–24) prior to the competition on April 25, and on-time completion of this documentation by the April 18 deadline — both tracked against the schedule in Table 6c.

---

## Team Meltdown - Tasks Distribution

### Project Assignments

**Table 6:** Team Member Roles and Assignments

| Name | Role | Grade |
|---|---|---|
| Adam Carbone | Advisor | Advisor |
| Jack Carbone | Advisor | Advisor |
| Adam Pakeltis | Mechanical | 12th |
| Alexander Holmes | Mechanical, Marketing | 11th |
| Ayden Moore | Mechanical | 11th |
| Benjamin Mackey | Documentation | 8th |
| Daniel George | Documentation | 11th |
| Dustin Hance | Software | 11th |
| Jason Kellhofer | Documentation | 9th |
| Jayden Craig | Mechanical, Marketing, Electrical | 10th |
| Kasey Kurzinger | Documentation, Mechanical | 8th |
| Kaydan Kerr | Documentation, Mechanical | 8th |
| Lukas Dauksa | Electrical | 11th |
| Mher Poghosyan | Documentation, Mechanical | 11th |
| Robert Rateno | Operator, Mechanical, Assembler | 10th |
| Richard Rowland | Documentation | 8th |
| Sultan Kazeem | Management, Finance, Assembler | 11th |
| Tom Kramer | Software, Documentation | 11th |
| Vincent Riha | Software | 10th |
| Xayden Minch | Software | 9th |
| Yash Jain | Electrical | 9th |

### Action Plan

**Table 6b:** Action Plan — Deliverables, Owners, and Deadlines

| Work Area | Deliverable | Lead(s) | Supporting Members | Deadline |
|---|---|---|---|---|
| Mechanical | Finalize chassis CAD model and release drawings for manufacturing | Adam Pakeltis, Robert Rateno | Ayden Moore, Jayden Craig, Alexander Holmes | Dec 7, 2025 |
| Mechanical | Waterjet the 6061-T6 aluminum top and bottom plates at Case Western think[box] (OMAX 5555) | Adam Carbone, Jack Carbone | Adam Pakeltis, Robert Rateno | Feb 15, 2026 |
| Mechanical | CNC-mill the 6061-T6 aluminum perimeter walls, bearing mount, and gearbox mount at Monode Marking Products | J.T. Mackey (industry), Adam Carbone | Robert Rateno, Kaydan Kerr | Mar 17, 2026 |
| Mechanical | Assemble chassis, install drive, weapon, and electronics | Robert Rateno, Sultan Kazeem | Ayden Moore, Kaydan Kerr, Kasey Kurzinger | Apr 7, 2026 |
| Electrical | Wire ESCs, kill switch, power distribution, Pi, and IMU | Lukas Dauksa, Yash Jain | Jayden Craig | Apr 10, 2026 |
| Software | Port meltybrain control from Python to C# on the Pi 4B | Tom Kramer, Dustin Hance | Vincent Riha, Xayden Minch | Mar 31, 2026 |
| Software | Integrate WT901 IMU and validate translation algorithm | Dustin Hance, Tom Kramer | Vincent Riha, Xayden Minch | Apr 14, 2026 |
| Documentation | Complete main.md, rubricCompliance tracker, supporting docs | Tom Kramer, Daniel George | Benjamin Mackey, Jason Kellhofer, Mher Poghosyan, Richard Rowland, Kasey Kurzinger | Apr 18, 2026 |
| Testing | Full-speed spin, maneuverability, impact, and endurance tests | Robert Rateno (operator), Adam Pakeltis | Full team | Apr 14–24, 2026 |
| Finance / Logistics | Track budget, place parts orders, handle registration | Sultan Kazeem | Jack Carbone, Adam Carbone | Ongoing → Apr 24, 2026 |
| Competition | Transport bot, pit crew, driver's meeting, judge interview | Robert Rateno, Jack Carbone, Adam Carbone | Full team | Apr 25, 2026 |

Each task is tracked in the team's shared Google Classroom. Leads are responsible for reporting status at weekly Tuesday meetings; blocking items are escalated to advisors Jack and Adam Carbone. A live TODO checklist is maintained in `todo.md` at the repository root, with items crossed off as they complete.

### Time Management

**Table 6c:** Season Timeline — Planned vs. Actual (2025–2026 Season)

| Phase | Planned Window | Actual Status | Key Deliverables |
|---|---|---|---|
| Introduction | Sep 24 – Oct 8, 2025 | Complete | Team roster finalized (19 HS students), advisors onboarded, season kickoff meeting held |
| Research & Influences | Oct 9 – Oct 31, 2025 | Complete | Survey of existing meltybrain spinners, analysis of Spinlayden 1.0 weaknesses, influence tables compiled |
| Design | Nov 1 – Dec 7, 2025 | Complete (minor late revisions through Jan) | Hexagonal chassis CAD, blade geometry, drive/weapon/power architecture locked |
| Engineering Drawings | Dec 8, 2025 – Jan 20, 2026 | Complete | Dimensioned drawings for Wall, Gearbox Mount, Bearing Mount released to shop |
| Procurement | Dec 2025 – Feb 2026 | Complete | Motors, ESCs, Pi, IMU, batteries, raw stock ordered; one parts delay absorbed with buffer |
| Manufacturing — Waterjet | Feb 1 – Feb 15, 2026 | Complete | 6061-T6 top and bottom hexagonal plates cut on the OMAX 5555 at Case Western think[box] |
| Manufacturing — CNC | Feb 15 – Mar 17, 2026 | Complete (slight overrun — finished Mar 24) | 6061-T6 perimeter walls, bearing mount, and gearbox mount machined at Monode Marking Products |
| Software — C# Port | Feb 3 – Mar 31, 2026 | Complete | Control software rewritten from Python to C# running on Pi 4B |
| Electrical Integration | Mar 18 – Apr 10, 2026 | Complete | ESCs, kill switch, Pi, IMU, and battery all wired and bench-tested |
| Assembly | Apr 1 – Apr 7, 2026 | Complete (PLA placeholder walls used during wiring; aluminum walls installed on return from CNC) | Full bot assembled |
| Testing | Apr 14 – Apr 24, 2026 | In Progress | Spin tests, driving tests, impact tests, battery runtime |
| Documentation | Ongoing → Apr 18, 2026 | In Progress | main.md, rubric tracker, supporting docs submitted by 11:59 PM April 18 |
| Competition | Apr 25, 2026 | Upcoming | Judge interview + combat matches at AWT Regional RoboBots |

Progress is reviewed at each Monday meeting against this timeline. Slippage (e.g., the week-long CNC overrun in March) was absorbed by compressing assembly while the PLA placeholder walls were used to continue wiring work in parallel. A meeting-by-meeting summary is provided in the following subsection.

### Meeting Minutes Summary

Team Meltdown met weekly on Mondays from 5:30–7:30 PM throughout the 2025–2026 season, with optional Saturday work sessions added in April. The following table records every meeting held this season: date, attendees, key topics, and decisions.

**Table 6e:** Meeting Minutes Summary (2025–2026 Season)

| # | Date | Phase | Attendees | Key Topics | Decisions / Outcomes |
|---|---|---|---|---|---|
| 1 | Sep 24, 2025 | Introduction | J. Craig, L. Dauksa, D. Hance, A. Holmes, S. Kazeem, J. Kellhofer, T. Kramer, X. Minch, A. Moore, M. Poghosyan, R. Rateno, V. Riha | Season overview, competition timeline, program expectations for new members | Started documentation; generated multiple bot design concepts |
| 2 | Oct 1, 2025 | Introduction | J. Craig, L. Dauksa, D. Hance, A. Holmes, S. Kazeem, J. Kellhofer, T. Kramer, X. Minch, A. Moore, M. Poghosyan, R. Rateno, V. Riha | Compared and analyzed proposed bot designs and names | Locked on **meltybrain "Spinlayden"** form factor |
| 3 | Oct 8, 2025 | Introduction | J. Craig, L. Dauksa, D. Hance, A. Holmes, S. Kazeem, J. Kellhofer, T. Kramer, X. Minch, A. Moore, M. Poghosyan, R. Rateno, V. Riha | Fusion 360 account setup, drive-testing old bots, team building | Began CAD modeling in Fusion 360 |
| 4 | Oct 15, 2025 | Design | J. Craig, L. Dauksa, D. Hance, A. Holmes, S. Kazeem, J. Kellhofer, T. Kramer, X. Minch, A. Moore, M. Poghosyan, R. Rateno, V. Riha | Chassis mounting holes, Pi replacement, WT901 IMU integration | Split into **two teams** (HS and JuniorBots) |
| 5 | Oct 22, 2025 | Design | L. Dauksa, D. Hance, A. Holmes, S. Kazeem, J. Kellhofer, T. Kramer, X. Minch, A. Moore, R. Rateno | Split into CAD/BOM group and Pi/software group | N/A |
| 6 | Oct 29, 2025 | Design | J. Craig, L. Dauksa, D. Hance, A. Holmes, Y. Jain, S. Kazeem, J. Kellhofer, T. Kramer, X. Minch, A. Moore, M. Poghosyan, R. Rateno, V. Riha | Continued parallel CAD and coding work | N/A |
| 7 | Nov 5, 2025 | Design / Docs | J. Craig, L. Dauksa, D. Hance, A. Holmes, Y. Jain, S. Kazeem, J. Kellhofer, T. Kramer, X. Minch, A. Moore, M. Poghosyan, R. Rateno, V. Riha | AWT documentation Zoom call; formed a Documentation sub-team | Assigned documentation responsibilities |
| 8 | Nov 12, 2025 | Design / Docs | J. Craig, L. Dauksa, D. Hance, A. Holmes, S. Kazeem, T. Kramer, X. Minch, A. Moore, R. Rateno, V. Riha | Reinforcing Spinlayden 1.0 weak points; CNC mill repair; ESC electrical test | N/A |
| 9 | Nov 19, 2025 | Design | L. Dauksa, A. Holmes, Y. Jain, S. Kazeem, J. Kellhofer, T. Kramer, X. Minch, R. Rateno, V. Riha | Mechanical engineering, software integration, electrical components | N/A |
| 10 | Dec 3, 2025 | Design | D. Hance, Y. Jain, J. Kellhofer, T. Kramer, X. Minch, A. Moore, A. Pakeltis, M. Poghosyan, R. Rateno | CAD learning session, electronics sourcing, Pi software work | N/A |
| 11 | Dec 10, 2025 | Design | D. Hance, Y. Jain, J. Kellhofer, T. Kramer, X. Minch, A. Moore, A. Pakeltis, M. Poghosyan, R. Rateno | Wireless code-server setup on Pi; weapon modeling | N/A |
| 12 | Dec 17, 2025 | Design | D. Hance, Y. Jain, J. Kellhofer, T. Kramer, X. Minch, A. Moore, A. Pakeltis, M. Poghosyan, R. Rateno | Portable power for Pi, Xbox-controller input, GitHub Copilot in code-server | N/A |
| 13 | Jan 7, 2026 | Build | A. Holmes, Y. Jain, J. Kellhofer, T. Kramer, X. Minch, A. Moore, M. Poghosyan, R. Rateno | Pi corruption; Xbox Bluetooth disconnects; CAD + weight reduction | Switch to **2.4 GHz USB radio controller**; order replacement Pi |
| 14 | Jan 14, 2026 | Build | D. Hance, A. Holmes, J. Kellhofer, X. Minch, A. Moore, A. Pakeltis, R. Rateno, V. Riha | Chassis material tradeoff (carbon fiber vs. titanium); BOM pricing | Selected carbon fiber as chassis material (later revised to 6061-T6 aluminum) |
| 15 | Jan 27, 2026 | Build | D. Hance, Y. Jain, J. Kellhofer, T. Kramer, A. Pakeltis, R. Rateno | Remote meeting (weather); component layout; software simplification | Switch to **SSH + Tailscale** (drop code-server) |
| 16 | Feb 3, 2026 | Build | S. Kazeem, D. Hance, T. Kramer, M. Poghosyan, R. Rateno, A. Pakeltis, Y. Jain, X. Minch, J. Kellhofer | Input-latency analysis on Python control loop | **Rewrite control software in C#** and deploy to Pi 4B |
| 17 | Feb 10, 2026 | Build | J. Craig, L. Dauksa, D. Hance, A. Holmes, Y. Jain, S. Kazeem, J. Kellhofer, T. Kramer, X. Minch, A. Moore, A. Pakeltis, M. Poghosyan, R. Rateno, V. Riha, D. George | Pi connected to shared monitor for team-wide development | N/A |
| 18 | Feb 17, 2026 | Build | J. Craig, L. Dauksa, D. Hance, A. Holmes, Y. Jain, S. Kazeem, J. Kellhofer, T. Kramer, X. Minch, A. Moore, A. Pakeltis, M. Poghosyan, R. Rateno, V. Riha, D. George | SD-card / equipment shortage; team building and coordination | Bring SD cards next meeting |
| 19 | Feb 24, 2026 | Build | J. Craig, L. Dauksa, D. Hance, A. Holmes, Y. Jain, S. Kazeem, J. Kellhofer, T. Kramer, X. Minch, A. Moore, A. Pakeltis, M. Poghosyan, R. Rateno, V. Riha, D. George, B. Mackey, R. Rowland, K. Kerr | Analyzed prior-year competition footage; onboarded 8th graders to codebase | **Merged** JuniorBots and HS teams into one unified Team Meltdown |
| 20 | Mar 3, 2026 | Build | J. Craig, L. Dauksa, D. Hance, A. Holmes, Y. Jain, T. Kramer, X. Minch, A. Moore, A. Pakeltis, M. Poghosyan, R. Rateno, V. Riha, D. George | Resolved electrical wiring issues; continued design and software docs | N/A |
| 21 | Mar 10, 2026 | Build | J. Craig, L. Dauksa, D. Hance, A. Holmes, Y. Jain, T. Kramer, X. Minch, A. Moore, A. Pakeltis, M. Poghosyan, R. Rateno, V. Riha, D. George | Pi 4B receives radio packets directly — no Pico translator needed | **Dropped Raspberry Pi Pico** from architecture |
| 22 | Mar 17, 2026 | Build | J. Craig, L. Dauksa, D. Hance, A. Holmes, Y. Jain, X. Minch, A. Moore, A. Pakeltis, M. Poghosyan, R. Rateno, V. Riha, D. George | Initial low-power spin test; 3D-printed fitment prototypes; software perf. data | **Apply Loc-Tite** to all fasteners |
| 23 | Mar 31, 2026 | Build | J. Craig, L. Dauksa, D. Hance, A. Holmes, X. Minch, A. Moore, A. Pakeltis, R. Rateno, D. George, T. Kramer | Installed 3D-printed prototype components onto chassis | N/A |
| 24 | Apr 3, 2026 | Build (optional) | D. Hance, X. Minch, R. Rateno, D. George, J. Kellhofer, B. Mackey, T. Kramer | Redesigned battery mount (Liperior 3S); CNC power-supply research | Purchase new CNC power supply |
| 25 | Apr 7, 2026 | Build | J. Craig, L. Dauksa, D. Hance, A. Holmes, X. Minch, A. Moore, A. Pakeltis, R. Rateno, D. George, T. Kramer, Y. Jain | Prototype chassis assembly; fastener inventory | Purchase additional #10-24 Phillips cap screws |
| 26 | Apr 11, 2026 | Build (optional, Sat) | J. Craig, L. Dauksa, D. Hance, A. Holmes, X. Minch, A. Moore, A. Pakeltis, R. Rateno, D. George, Y. Jain | CNC power-supply installed; prototype assembly complete; prototype testing | N/A |
| 27 | Apr 14, 2026 | Build / Docs | J. Craig, L. Dauksa, D. Hance, A. Holmes, X. Minch, A. Moore, A. Pakeltis, R. Rateno, D. George, T. Kramer, Y. Jain, B. Mackey | Disassembled prototype for reuse; metal-chassis assembly begun | **Converted docs to Markdown** and created GitHub repo |
| 28 | Apr 18, 2026 | Docs / Testing (optional, Sat) | J. Craig, L. Dauksa, D. Hance, A. Holmes, X. Minch, A. Moore, A. Pakeltis, R. Rateno, D. George, T. Kramer, Y. Jain, B. Mackey | Final session before AWT 2026 — wrapping documentation, continuing build/test | Finalize documentation for 11:59 PM submission |

All meetings ran 5:30–7:30 PM unless noted (Apr 11 and Apr 18 Saturday sessions ran 10:00 AM – 1:00 PM). Attendee initials match the full team roster in the *Team Members* table above.

### Documentation Contributions

The Documentation team — Benjamin Mackey, Daniel George, Jason Kellhofer, Kasey Kurzinger, Kaydan Kerr, Mher Poghosyan, Richard Rowland, and Tom Kramer — wrote, reviewed, and edited this submission as a group effort. Each documentation member owned one or more sections of this document; drafts were reviewed in weekly Monday meetings and edited collaboratively before being merged into the final submission. Writing credit is shared across the team.

**Table 6d:** Documentation Section Ownership

| Section | Lead Contributor(s) |
|---|---|
| Cover Page, Meet the Robotics Team, Table of Contents | Tom Kramer |
| About Riverside | Daniel George |
| Our Partners (Monode, Arc Technology, Show Studio) | Mher Poghosyan |
| Team Biographies | Benjamin Mackey, Jason Kellhofer (compilation); individual bios written by each team member |
| Mentor / Advisor Biographies | Kasey Kurzinger |
| Acknowledgements | Richard Rowland |
| Design — Influences, Previous Bot, What Changed | Daniel George, Mher Poghosyan |
| Project Overview — General Info, Sponsors, Advisors, Manufacturing, Bot Description, Objective | Kaydan Kerr |
| Project Overview — Team Members, Deliverables, Key Milestones, Constraints | Jason Kellhofer |
| Team Meltdown — Tasks Distribution (Project Assignments, Action Plan, Time Management) | Tom Kramer |
| Team Meltdown — Documentation Contributions (Section Ownership, Table 6d) | Tom Kramer (compilation on behalf of the Documentation team) |
| Team Procedures — Material Management, Bill of Materials, Budget | Kasey Kurzinger |
| Team Procedures — Material Selection, Fabrication, Inventory | Mher Poghosyan, Kaydan Kerr |
| Team Procedures — Data Management, Our Component Philosophy | Richard Rowland |
| Design Process — Research, Strategy, Overview, Key Stats | Benjamin Mackey |
| Design Process — Analysis & Conceptualization, Design Motivation, Research Methods, Refinement | Daniel George |
| Design Process — Risk Analysis, Structural Analysis (FMEA) | Tom Kramer |
| Design Process — CAD Models, Engineering Drawing Set | Mher Poghosyan (write-up); CAD and dimensioned drawings by Robby Rateno (Design Team) |
| Design Process — Weapon System, Drive System, Power System | Jason Kellhofer, Kaydan Kerr |
| Design Process — Wiring Schematic, Testing Results | Tom Kramer (with Software Team) |
| Closing Remarks | Richard Rowland, Benjamin Mackey |
| Meeting Minutes Summary (Table 6e) — weekly minutes Sep 24, 2025 – Apr 18, 2026 | Rotating scribe duty across the Documentation team. Primary scribes: Benjamin Mackey, Jason Kellhofer, Richard Rowland, Kasey Kurzinger, Kaydan Kerr, Daniel George, Mher Poghosyan, Tom Kramer |

Images used throughout this document are credited in their individual figure captions. CAD renders and engineering drawings were produced by the Design Team (Robby Rateno leading the dimensioned drawing set). Physical build, manufacturing, and chassis assembly photos were taken by the Mechanical Team. Raspberry Pi, WT901 IMU, and wiring photos were taken by the Software Team. The team shirt photo (Figure preceding the Design section) was captured from the 2026 Riverside Robotics shirt artwork by the Marketing sub-team.

---

## Team Procedures

### Material Management

Material Management is done by keeping an inventory of parts that are left from previous years. We try to reuse as many unused and old parts as possible to save money and time when designing the bot. Some parts need replacement or are new this year compared to what we already have. Listed below is our parts list for Riverside Robotics Team Spinlayden this year, and the Budget.

#### Parts List

**Table 7:** Bill of Materials — Parts List

| Buyer | Category | Part | Unit Price | Qty | Total Cost |
|---|---|---|---|-----|---|
| Monode (Donated) | Chassis | 6061-T6 Aluminum Bar, 3/8" Thick × 8" Wide — Wall Stock (donated by Monode Marking Products) | $0.00 | — | $0.00 |
| Monode (Donated) | Chassis | 6061-T6 Aluminum Sheet, 1/8" Thick — Plate Stock (donated by Monode Marking Products) | $0.00 | — | $0.00 |
| Riverside | Weapon | Everbilt 1/2 in.-13 × 2 in. Zinc Plated Hex Bolt (50-Pack), SKU 800980 | $39.32 | 1 | $39.32 |
| Riverside | Drive | R8-2RS Sealed Ball Bearings, 1/2" × 1-1/8" × 5/16" (20-pack) | $12.99 | 1 | $12.99 |
| Riverside | Brain | Raspberry Pi 4B, 8 GB RAM (1 primary + 1 spare — Pi identified as a high-failure point on Spinlayden 1.0) | $97.99 | 2 | $195.98 |
| Riverside | Power | XT60 Connector & Wire Covers (8-pack) | $12.99 | 1 | $12.99 |
| Riverside | Chassis | Kraken Bond KH 62 Red Threadlocker | $9.99 | 1 | $9.99 |
| Riverside | Power, Brain | 63-37 Tin Lead Rosin Core Solder Wire (0.8 mm, 100 g) | $11.99 | 1 | $11.99 |
| Riverside | Brain | ELEGOO 120-pc Multicolored Dupont Wire | $6.98 | 1 | $6.98 |
| Riverside | Chassis | eSUN TPE-83A Flexible Filament, 1.75 mm | $28.11 | 1 | $28.11 |
| Riverside | Chassis | CR PETG 3D Printer Filament, 1.75 mm, 1 kg | $12.99 | 1 | $12.99 |
| Riverside | Drive | 1045 Carbon Steel Rotary Shaft, 3", 1/2" Dia | $9.25 | 4 | $37.00 |
| Riverside | Drive | Terre Products 1.75" V-Groove Drive Pulley | $16.92 | 6 | $101.52 |
| Riverside | Drive | Dayco 4L160 Utility V-Belt | $7.29 | 1 | $7.29 |
| Riverside | Chassis | #10-24 × 3/8" Hex Socket Button Head Cap Screws (100-pack) | $67.00 | 1 | $67.00 |
| Riverside | Weapon | #10-24 × 3/4" Flat Head Socket Cap Screws, 304 SS (50-pack) | $7.98 | 1 | $7.98 |
| Riverside | Safety | Polycarbonate Safety Glasses (12-pack) | $23.39 | 1 | $23.39 |
| Riverside | Safety | ANSI A5 Polyurethane Coated Work Gloves, Medium (12-pack) | $81.43 | 1 | $81.43 |
| Team (Owned) | Drive | T81 Hub, 1/2" Hex Shaft | $4.50 | 8 | $36.00 |
| Team (Owned) | Drive | BaneBots Wheel, 3-7/8" × 0.8" | $4.25 | 12 | $51.00 |
| Team (Owned) | Drive | EZRUN 3660 SL G2 Motor | $81.00 | 2 | $162.00 |
| Team (Owned) | Drive | EZRUN MAX10 SCT ESC | $119.00 | 2 | $238.00 |
| Team (Owned) | Drive | LANIAKEA Ball Bearing, 5/8" (16-pack) | $16.99 | 1 | $16.99 |
| Team (Owned) | Power | Liperior 3S 3200 mAh 11.1V LiPo Battery (XT60) — included with the AWT RoboBots kit provided by Riverside High School | $0.00 | 4 | $0.00 |
| Team (Owned) | Control | 2.4 GHz USB radio transmitter (white) — included with the AWT RoboBots kit | $0.00 | 1 | $0.00 |
| Team (Owned) | Control | FS-iA6B 2.4 GHz receiver — included with the AWT RoboBots kit | $0.00 | 1 | $0.00 |
| Team (Owned) | Power | MS-05 Kill Switch | $75.00 | 1 | $75.00 |
| Advisors | Chassis, Weapon | Lunyee 3018 Pro Ultra CNC Machine, 500W | $499.00 | 1 | $499.00 |
| Advisors (students reimbursed $15 each) | Club | Custom Ink Gildan Softstyle T-shirts, Black — 60 shirts, Receipt #87094381 | $965.25 | 1 | $965.25 |
| Advisors | Drive | WT901 9-axis IMU / Gyro (USB, 200 Hz) | $32.65 | 2 | $65.30 |
| Advisors | Drive | Milwaukee Hex Drill Bit Packs | $8.55 | 4 | $34.20 |
| Advisors | Chassis | PLA Filament (student-sourced) | $20.00 | 1 | $20.00 |
| Advisors | Drive | P6S Gearbox: Standard Duty, 20:1 (2 new + 2 owned) | $63.65 | 4 | $254.60 |

#### Budget Summary

**Table 8:** Budget Summary by Funding Source

| Funding Source | Total Value | New Expenditures (2025-2026) |
|---|---|---|
| Riverside High School (PO 219831) | $745.00 | $745.00 |
| Advisors — Jack Carbone (net after student shirt reimbursement) | $938.35 | $811.05 |
| Students (60 × $15 shirt reimbursement to Jack) | $900.00 | $900.00 |
| Team (Previously Owned, incl. AWT RoboBots kit) | $578.99 | $0.00 |
| Monode Marking Products (In-Kind — chassis metal + machining) | $388.38 | $0.00 |
| **Total** | **$3,550.72** | **$2,456.05** |

### Our Component Philosophy

Spinlayden is based on Riverside Robotics' meltybrain full-body spinner of the same name from the previous season. Iterating on the existing design provides several key engineering advantages over a ground-up redesign. The team can leverage the experience of returning members, who understand the original design decisions and key design considerations. Spinlayden 1.0's competition performance serves as a baseline for identifying areas of improvement, allowing the team to address known deficiencies systematically. Additionally, reusing the existing platform enables the team to carry over spare and existing components, reducing both cost and procurement lead time. CAD development time is also reduced, as component dimensions and 3D models from the previous season can be directly referenced.

Like last year, Spinlayden uses a custom-fabricated chassis to optimize our performance, space, and weight. While the chassis may look the same from the outside, we have redesigned it from the ground up. This year we are using a different weight reduction that allows us to give better protection to the internal components, especially since the controller inputs are processed on a Raspberry Pi inside the bot itself this year instead of having the computing be done on a laptop that connects to the bot.

Spinlayden's chassis also benefits from hexagonal structural rigidity. The six-sided geometry provides inherent resistance to impact loading from any angle, which is essential for a combat robot, and also provides six mounting faces for the impact bolt assemblies. The combination of symmetric weight distribution, custom-fabricated components, and precision machining enables balanced mass distribution across the chassis, which is critical for stable rotation and precise translational control during operation.

### Material Selection

Choosing the right materials is critical for a 15 lb combat robot where every ounce matters. Each material on Spinlayden was selected to balance strength, weight, machinability, and cost.

#### Chassis — 6061 Aluminum

The chassis is fabricated from **6061-T6 aluminum** in two thicknesses: 3/8" bar stock for the walls and 1/8" sheet for the top and bottom plates. 6061 was selected for several reasons:

- **Strength-to-weight ratio:** At a density of 0.098 lb/in³ and a tensile strength of ~45 ksi, 6061 provides excellent structural performance without consuming our weight budget. The full chassis comes in at approximately 12.6 lbs, leaving room for electronics and impact hardware.
- **Machinability:** 6061 is one of the most machinable aluminum alloys, which was essential given our fabrication methods. It cuts cleanly on both the OMAX 5555 waterjet and Monode's CNC mills, reducing fabrication time and cost.
- **Cost-effectiveness:** 6061 is widely available and affordable compared to aerospace-grade alternatives, keeping us within our budget.
- **Corrosion resistance:** The T6 temper provides good corrosion resistance without additional surface treatment, reducing post-processing steps.

**Alternatives considered:**
- **7075 Aluminum** — Roughly 30% stronger than 6061, but significantly harder to machine, more expensive, and less weldable. The added strength was not necessary given our hexagonal design already provides excellent rigidity.
- **Carbon Fiber** — Discussed early in the season as a potential option. While carbon fiber offers a superior strength-to-weight ratio, it is brittle under point-impact loading (a certainty in combat), difficult to machine into complex shapes, and substantially more expensive. A shattered carbon fiber panel mid-match would be catastrophic.
- **Titanium** — Excellent strength and low weight, but roughly 5–10× the cost of aluminum and much harder to machine. Our sponsors' equipment is optimized for aluminum and steel, making titanium impractical.

#### Impact Bolts — Carbon Steel

Spinlayden 2.0's six impact weapons are **1/2" carbon steel hex bolts** threaded through the perimeter chassis walls — one per face. When the chassis spins at 645.6 RPM, the protruding bolt shank and head become the primary striking surface, delivering impact force concentrated through a small contact area.

- **Strength:** Carbon steel hex bolts provide good tensile and shear strength, resisting deformation under repeated high-energy impacts at combat speeds.
- **Simplicity:** Off-the-shelf hex bolts eliminate custom machining for the weapon system, reducing fabrication time and cost while making field replacement between matches fast and straightforward.
- **Replaceability:** A bent or damaged bolt can be swapped in seconds with a standard wrench — no machined spare parts required.

**Why hex bolts over machined blades:**
The previous design used custom-machined A516 carbon steel blade pieces, which required precision fabrication and were difficult to replace under time pressure. Switching to standard hex bolts reduces the weapon to a commodity part available at any hardware store, while the blunt bolt-head geometry delivers brute-force impact rather than relying on blade geometry for damage.

#### Rotary Shaft — 1045 Carbon Steel

The rotary shafts are **1045 medium carbon steel**, selected for its good balance of strength (tensile strength ~85 ksi) and machinability. 1045 is a standard choice for shafts and axles because it can be easily turned on a lathe while providing adequate fatigue resistance for rotational loads.

#### 3D Printed Components — PLA, PETG, and TPE

All internal, non-structural components are 3D printed using materials chosen for their specific properties:

- **PLA** — Used for rigid internal mounts and brackets. Final parts are printed at 100% infill for maximum strength; prototypes at 15% infill for rapid iteration.
- **CR PETG** — Used where higher temperature resistance or slight flexibility is needed compared to PLA.
- **eSUN TPE-83A** — A flexible filament used for vibration-dampening mounts and components that need to absorb shock without cracking.

### Fabrication

Fabrication is central to Spinlayden's design. As a full-body spinner, the robot's chassis is the weapon system — rotating at high angular velocity, the chassis impacts opposing robots and transfers significant kinetic energy on contact. The following fabrication methods were used to manufacture Spinlayden's components:

#### Waterjet Cutting

The top and bottom hexagonal plates were cut using an **OMAX 5555 Waterjet Cutter** at [Case Western Reserve University's think[box]](https://case.edu/thinkbox/equipment/metal-shop/waterjet-cutter). Waterjet cutting allowed us to precisely cut our plates cost-effectively, with a dimensional accuracy of ±0.001 inches (25.4 μm) and a maximum material capacity of 48 × 40 × 8 inches.

The machine runs at **$1 per minute** of run time. Each nest of two hexagons took approximately 27 minutes, costing roughly **$54 per pair** of plates ($27 × 2 nests).

*Figure 4: OMAX 5555 waterjet controller displaying the hexagonal plate cutting paths. Photo: Mechanical Team.*

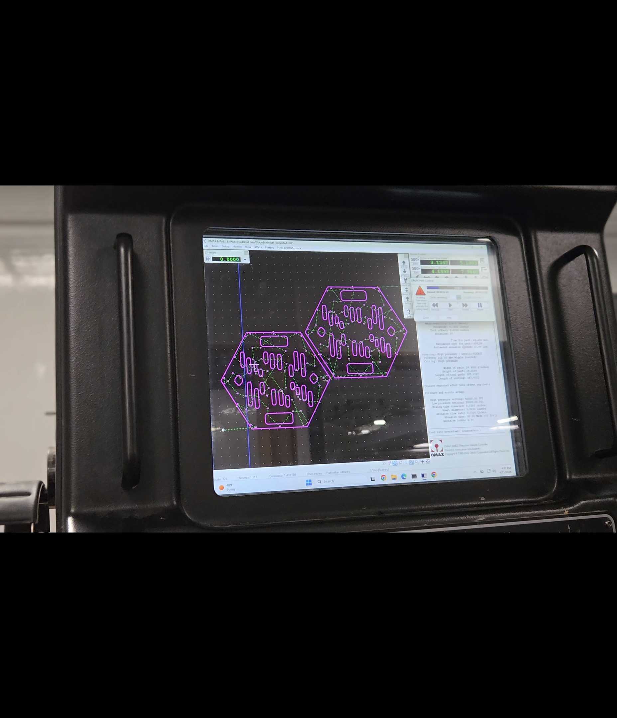
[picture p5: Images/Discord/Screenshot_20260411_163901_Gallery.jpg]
OMAX 5555 waterjet controller screen showing hexagonal plate cutting paths


*Figure 5: Waterjet-cut 6061-T6 aluminum chassis plates — hexagonal top and bottom plates with weight reduction cutouts. Photo: Mechanical Team.*

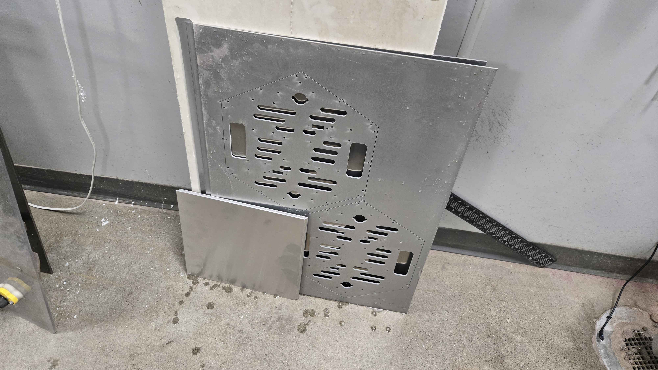
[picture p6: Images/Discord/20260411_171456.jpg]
Waterjet-cut aluminum chassis plates with hexagonal geometry and weight reduction cutouts


#### CNC Milling

CNC milling was provided by our industry sponsor, **Monode Marking Products**. Monode machined our parts using their in-house CNC equipment, with each part typically taking a couple of hours to complete.

#### 3D Printing (FDM)

All internal components were 3D printed using **standard PLA filament**. Prototypes were printed at **15% infill** for rapid iteration, while final internal parts and backup/replacement components were printed at **solid (100%) infill** for maximum strength and durability.

#### Assembly Process

The step-by-step procedure used to assemble Spinlayden 2.0 from its fabricated parts. Two sub-assemblies run in parallel to the main chassis build:

- **Wall prep (parallel):** Any bolts or fasteners that need to be pre-installed into the perimeter walls are threaded in *before* the walls are mounted to the bottom plate. This is done first because access is easier with the walls off the chassis.
- **Gearbox sub-assembly (parallel):** Each BaneBots P61 gearbox is attached to its machined gearbox mount separately from the main chassis.

Once both sub-assemblies are ready, the main build proceeds in the following order:

1. **Start with the bottom plate.** The waterjet-cut 6061-T6 aluminum bottom plate is the foundation of the assembly — every other component mounts to it.
2. **Mount the walls.** Attach the (pre-fastened) perimeter walls to the bottom plate.
3. **Attach the gearbox mounts to the bottom plate.** Mount the completed gearbox sub-assemblies onto the bottom plate.
4. **Attach the belt and tensioner.** Mount the drive belt and tensioner to the bottom plate at the same stage as the gearbox mounts.
5. **Install the Pi mount.** With the gearboxes in place, install the Pi mount onto the assembly.
6. **Install the electronics.** Install the Raspberry Pi first, then the ESCs.
7. **Attach the top plate.** Close out the build by attaching the top plate.

#### Physical Assembly

The following photos document the build progression of Spinlayden 2.0 — from electronics mounting on the waterjet-cut 6061 aluminum bottom plate through full-chassis wiring integration. To avoid losing schedule time while waiting on the CNC shop, the team 3D-printed a full set of placeholder perimeter walls and a top plate in PLA so that wiring, component fitment, and layout could be validated in parallel with external machining. The images also show the 3D-printed PLA internal components (battery bracket, Pi/IMU housing) in their final mounted positions.

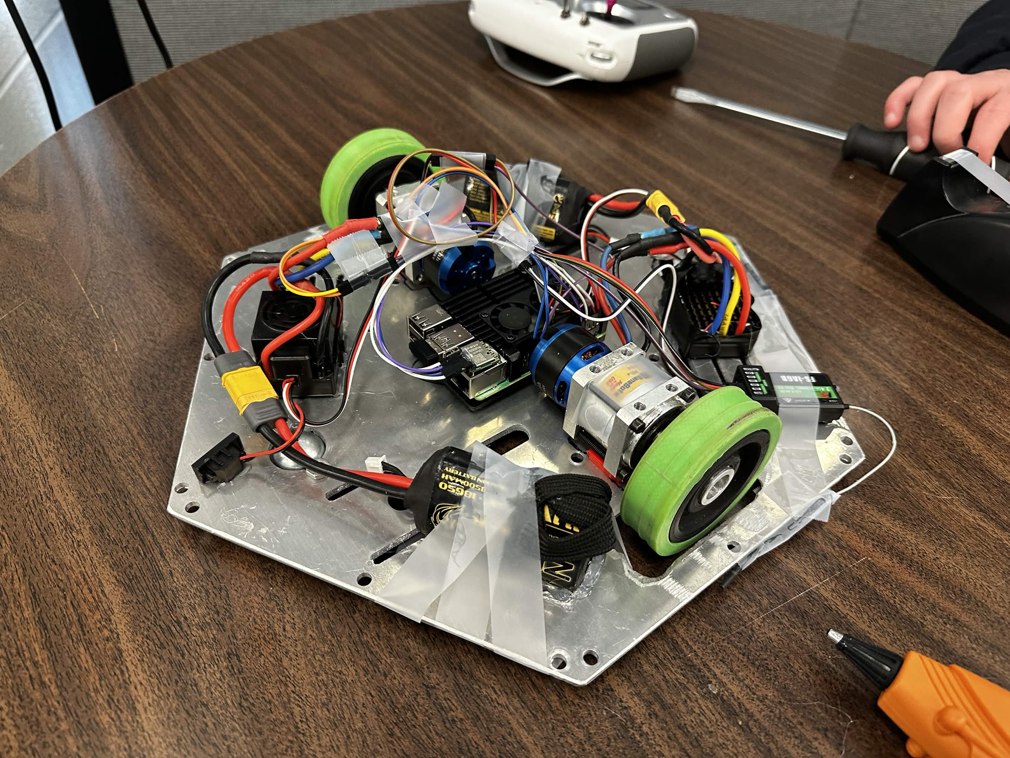
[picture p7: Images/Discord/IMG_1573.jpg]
In-progress assembly of Spinlayden 2.0 on the waterjet-cut hex bottom plate showing Raspberry Pi, dual ESCs, BaneBots P61 gearboxes, green drive wheels, and battery XT90 connectors mounted before perimeter walls were installed


*Figure 15: In-progress assembly — waterjet-cut 6061 aluminum bottom plate with the Raspberry Pi 4B, dual EZRUN MAX10 ESCs, BaneBots P61 gearboxes, green BaneBots drive wheels, and battery XT90 interconnects mounted prior to perimeter wall installation. Photo: Mechanical Team.*

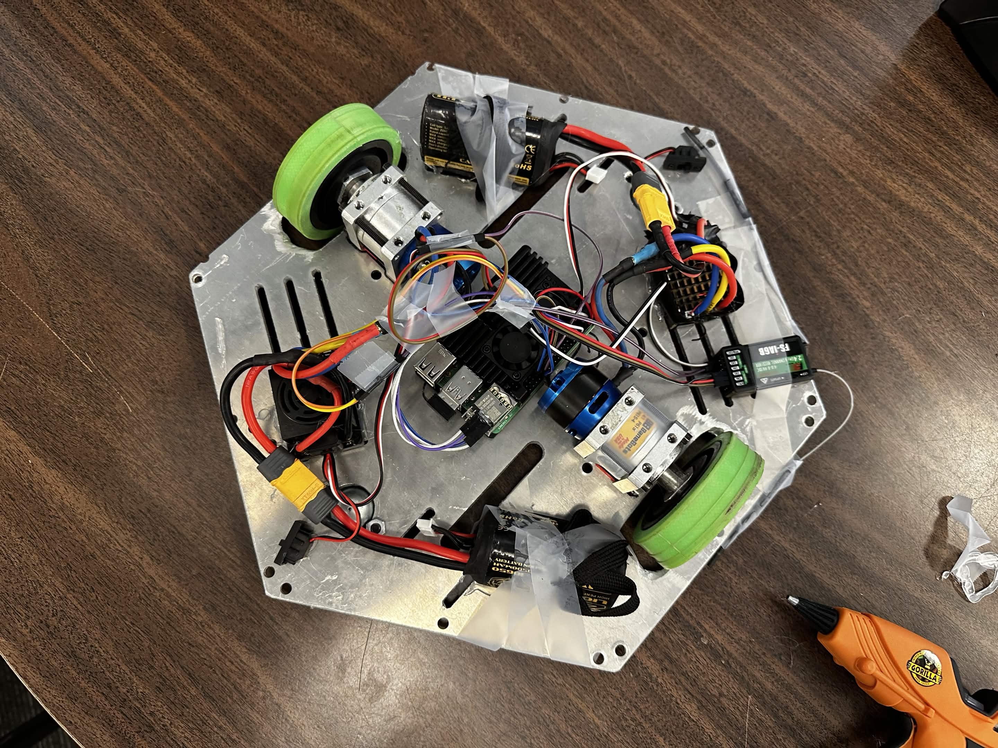
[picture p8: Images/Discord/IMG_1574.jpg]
Top-down view of the same assembly stage showing symmetric layout of electronics and drive components on the hex bottom plate


*Figure 15b: Top-down view of the same assembly stage showing the symmetric electronics and drive layout around the central Raspberry Pi housing. Photo: Mechanical Team.*

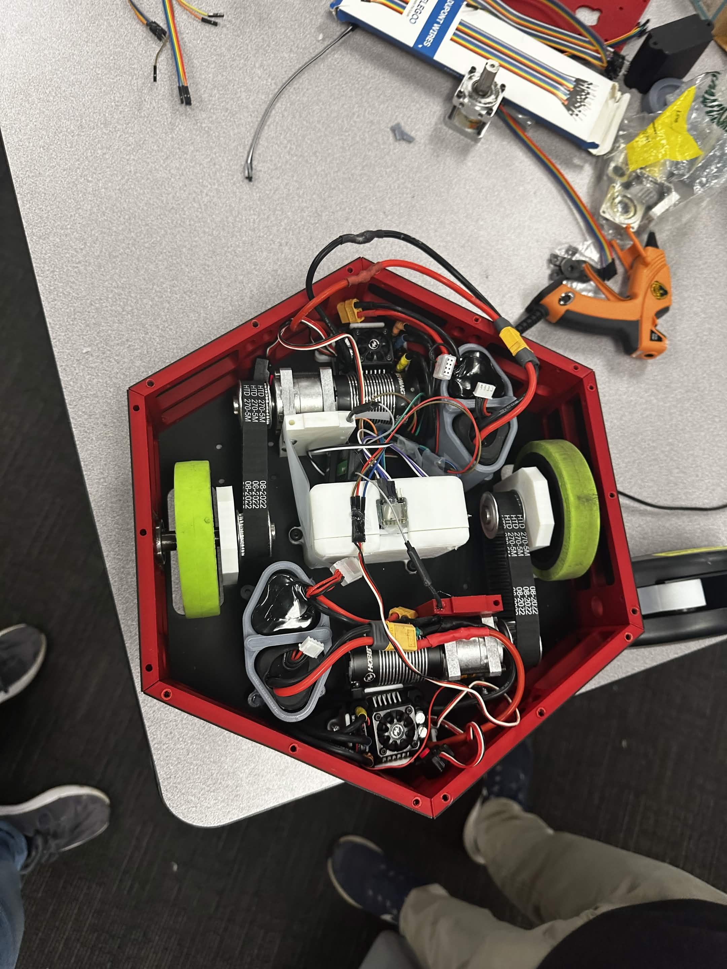
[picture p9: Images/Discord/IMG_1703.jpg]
Wiring-integration assembly with 3D-printed PLA placeholder walls installed, top plate removed for internal view showing the complete drive and power layout


*Figure 16: Wiring-integration assembly — the red and black perimeter walls are 3D-printed PLA placeholders, printed in-house so the team could validate electronics layout, wiring routing, and component fitment in parallel with the CNC-milled aluminum walls being fabricated off-site. Top plate removed for internal view. Final positioning of the dual BaneBots gearboxes, drive wheels, and the central Pi/IMU control stack is identical to the end-state aluminum build. Photo: Mechanical Team.*

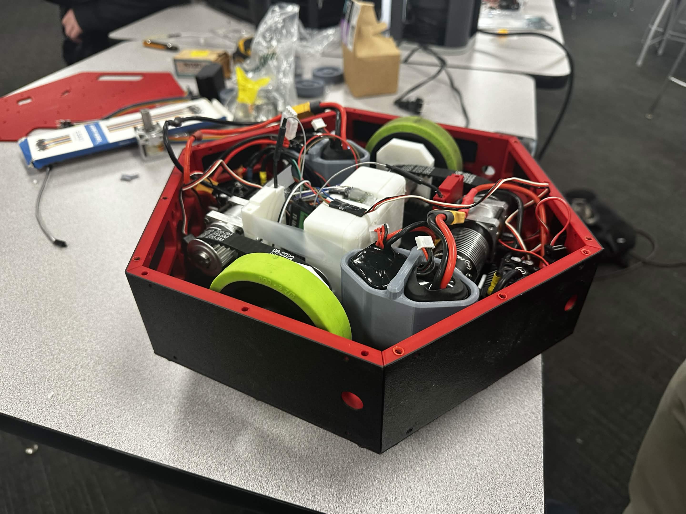
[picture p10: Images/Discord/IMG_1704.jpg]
Angled side view of the wiring-integration assembly showing the 3D-printed PLA placeholder walls, 3D-printed battery bracket, and 3D-printed Pi housing


*Figure 16b: Angled view of the same wiring-integration build — every colored wall panel, the top plate, the white battery bracket, and the Pi/IMU housing visible here are 3D-printed PLA parts. The colored walls and top plate are placeholders that will be swapped out for the anodized 6061 aluminum parts once they return from the CNC shop; the internal brackets (battery, Pi/IMU) are final flight hardware, printed at 100% infill per the internal-components fabrication spec. Photo: Mechanical Team.*

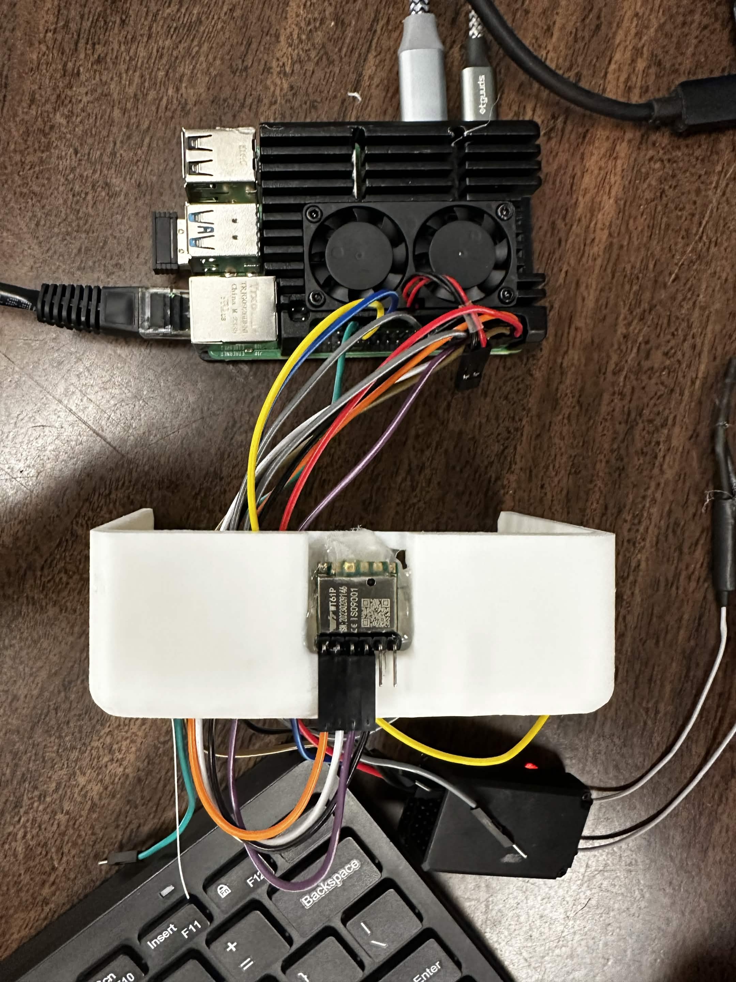
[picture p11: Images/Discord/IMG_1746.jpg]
Close-up of the Raspberry Pi 4B with dual-fan heatsink case and the WT901 IMU mounted in a 3D-printed PLA bracket directly beneath it


*Figure 16c: Detail view of the 3D-printed PLA IMU mounting bracket supporting the WT901 9-axis IMU directly beneath the Raspberry Pi 4B — the printed enclosure provides a rigid, vibration-isolated mount for the gyroscope during high-RPM operation. Photo: Software Team.*

### Inventory

The following table lists the tools and equipment available to Riverside Robotics for fabrication, assembly, and maintenance of Spinlayden. Keeping an accurate inventory ensures the team can plan work sessions effectively and identify when replacements or additional tools are needed.

**Table 9:** Tools and Equipment Inventory

| Item | Quantity | Type | Condition |
|---|---|---|---|
| DeWalt Drill | 1 | Power Tool | Good |
| DeWalt Impact Driver | 1 | Power Tool | Good |
| Ryobi Drill | 1 | Power Tool | Functional (bad battery) |
| Hex Allen Key Set | Multiple | Hand Tool | Good |
| Pliers (assorted) | Multiple | Hand Tool | Good |
| Drill/Impact Bit Sets | Multiple | Accessories | Good |
| Wrench Set (assorted) | Multiple | Hand Tool | Good |
| Lunyee 3018 Pro Ultra CNC Machine (500W) | 1 | CNC Equipment | Good |
| 3D Printer (PLA/PETG/TPE capable) | 1 | 3D Printing | Good |
| Soldering Iron | 1 | Electronics | Good |
| Polycarbonate Safety Glasses | 12 | Safety | New |
| ANSI A5 Polyurethane Coated Work Gloves | 12 | Safety | New |

### Data Management

Team Meltdown uses a combination of version-controlled repositories, cloud storage, and collaborative design platforms to manage all project files and ensure that every team member has access to the latest versions of our work.

**Software and Documentation — GitHub**
All control software for Spinlayden 2.0 is maintained in a dedicated GitHub repository. The codebase is version-controlled using Git, allowing the software team to track changes, revert to previous versions, and collaborate without overwriting each other's work. A separate GitHub repository is used for all competition documentation, including this document, meeting notes, team biographies, and supporting files. Using Git for documentation ensures a complete revision history and makes it easy to identify who contributed what and when.

**CAD Models — Autodesk Fusion 360 Shared Hub**
All mechanical design work is done in Autodesk Fusion 360. The design team operates within a shared Fusion 360 hub, giving all members access to the latest version of every part, assembly, and drawing. Fusion 360's built-in version history tracks each iteration of every component, making it straightforward to compare revisions or roll back changes if a design modification does not perform as expected.

**General File Sharing — Shared Drive**
For files that do not fit neatly into a code repository or a CAD platform — such as reference images, sponsor logos, budget spreadsheets, and rubric documents — the team uses a shared drive folder. This central location ensures that non-technical files are accessible to all team members regardless of which subteam they belong to.

This multi-platform approach ensures that each type of project data lives in the tool best suited to manage it, while keeping everything accessible and version-tracked for the full team.

---

## Design Process

### Research

Research for Spinlayden 2.0 was driven by two questions: *what did Spinlayden 1.0 teach us?* and *what does the rest of the meltybrain field look like?* The team drew on three primary sources.

**Spinlayden 1.0 (in-house baseline):** The team's own 2024–2025 competition robot served as the primary reference platform. Returning members walked newer members through the original design decisions, competition footage was reviewed, and every failure point from the 2025 season was catalogued — see the Influences section for the full list and the Problem/Solution table (Table 2) for how each weakness was addressed in 2.0.

**Prior AWT RoboBots competition footage:** The team studied footage of past AWT Regional RoboBots matches at Lakeland Community College, focusing on how full-body spinners performed against the variety of bots typically fielded (wedges, vertical spinners, control bots). Key observations fed directly into our combat strategy (see *Design Process → Strategy*) — notably the importance of spin-up time management and the need to maintain translational mobility even while spinning.

**Public meltybrain references:** The open-source **OpenMelt** project on GitHub was reviewed as a reference for the physics of meltybrain control (gyroscope integration, translation pulse timing, and RPM-to-tip-velocity relationships). The C# rewrite of Spinlayden's control software borrows its overall control-loop structure from OpenMelt while reimplementing it natively on the Raspberry Pi 4B; see *Design Process → Drive System Details* for the implementation.

**Findings that shaped the 2.0 design:**

- Full-body spinners that maintain spin throughout the match outperform bots that repeatedly spin-up and spin-down — motivating the emphasis on battery runtime, motor headroom, and a single always-spinning combat mode in our strategy.
- Exposed internal components are the most common failure mode for full-body spinners under repeated impact — motivating the 2.0 layout change that pushes all electronics inward away from the walls.
- Blade-geometry weapons (custom-machined tips) are harder to field-service than standard hardware — motivating the switch from machined blades to 1/2" carbon steel hex bolts that can be swapped with a wrench between matches.
- Python-based meltybrain control loops exhibit measurable timing jitter on a Pi 4B compared to compiled alternatives — motivating the rewrite to C# for Spinlayden 2.0.

### Strategy

#### Offensive Strategies

- Rush opponents at 1-2 ft/s using ~0.75 hp motors to seize control and force reactive defenses
- Spin at 645.6 RPM to deflect attacks with a ~26.9 mph bolt barrier, priming for counterstrikes
- Strike with 15-lb spinning mass and six impact bolts (~78 J/rotation) to exploit opponent vulnerabilities
- Sustain 645.6 RPM spins and agile steering to keep opponents defensive and disoriented
- Recover from flips in ~2 seconds using double-sided design to resume aggressive maneuvers

#### Defensive Strategy

- Spin at 645.6 RPM to generate a 20–30 mph perimeter steel barrier, deflecting attacks and protecting internal components
- Accelerate at 1-2 ft/s to retreat if needed from opponents, gaining time to recover and spin up
- Utilize weight reduction cutouts in 6061 aluminum chassis for passive airflow during rotational operation
- Maintain rotational velocity via two-motor drive system while maneuvering, minimizing stationary vulnerabilities. Two operators — one for drivetrain control and one for system mode management.
- Operate effectively when flipped using double-sided design, reducing downtime from impacts

### Overview

Spinlayden 2.0 is a 15-pound meltybrain full-body spinner designed for the AWT Regional RoboBots Competition. The robot builds on the foundation established by Spinlayden 1.0 during the 2025 season, addressing every major weakness identified during that campaign while retaining the core hexagonal meltybrain concept that proved viable in competition. The chassis is machined from 6061-T6 aluminum and carries six 1/2" carbon steel hex bolts threaded through its perimeter walls as impact weapons, delivering approximately 78 joules of kinetic energy per rotation at a spin rate of 645.6 RPM. A Raspberry Pi 4B running custom C# control software processes IMU data from a WT901 gyroscope to enable simultaneous rotation and translation — the defining capability of a meltybrain drive system. Key improvements over the previous design include partial-depth weight reduction pockets replacing through-holes, repositioned internal components for better impact protection, a dedicated 3D-printed Raspberry Pi housing, 1/2" carbon steel hex bolt weapons replacing the previous blade system, and a 2.4 GHz radio link replacing the unreliable Bluetooth connection.

### Key Stats

- **Weight (base build):** 13.5 lbs — measured current configuration, no Speaker or RGB lighting installed
- **Weight (competition target):** 15 lbs — AWT weight cap. The remaining 1.5 lbs of budget is allocated to the planned onboard Speaker, RGB chassis lighting, and any ballast needed to bring the bot up to the class limit for final competition tuning.
- **Weapon Speed:** 645.6 RPM (~26.9 mph tip speed)
- **Kinetic Energy:** ~78 J per rotation at the 15 lb competition target (~70 J in the 13.5 lb base configuration — KE scales linearly with total spinning mass at fixed RPM, so the final ballast/accessory mass directly increases weapon energy)
- **Motor Power:** ~0.75 hp (drive and weapon combined)
- **Translational Speed:** 1-2 ft/s while spinning (unchanged between 13.5 lb and 15 lb configurations — top translational speed is set by wheel RPM and circumference, not by robot mass)
- **Translational Acceleration:** roughly 10% higher in the 13.5 lb base build than at the 15 lb target (a ∝ 1/m in the torque-limited regime); Robby is tuned against the heavier competition configuration, so in-match handling is specified against the 15 lb number
- **Spin-up Time to Weapon Speed:** approximately 10% faster in the 13.5 lb base build than at 15 lb, since spin-up time scales with moment of inertia — the extra mass at competition weight trades a slightly slower ramp for higher delivered kinetic energy
- **Material:** 6061 aluminum chassis, 1/2" carbon steel hex bolts (impact weapons)
- **Impact Bolts:** 6 × 1/2" carbon steel hex bolts, one per chassis face
- **Torque:** ~5 Nm per drive motor (estimated, 20:1 reduction)

### Analysis and Conceptualization

We began by analyzing the previous iteration of the robot from the 2025 season. Using the original design as a reference platform, the team identified and addressed the deficiencies and failure modes present in last year's design.

With the Robotics program expanding significantly in membership — from 8 students last season to a 19-student high school roster this year plus two middle school JuniorBots teams — Team Meltdown set out to build on the previous design. After forming the team, we took several measures:

- Watched previous AWT competitions and noted the performance of other bots and on what design they relied on
- Reviewed the prior Riverside design and analyzed the most significant obstacles and problems
- Whiteboarded various ideas, as well as comparing their advantages and weaknesses
- Started a basic CAD design in Fusion 360 that we could build on over the season

*Figure 6: Early hand-drawn concept sketch of Spinlayden 2026 — exploring chassis geometry, wall count, and proposed new components (gearboxes, shelling) before moving into CAD. Sketch: Design Team.*

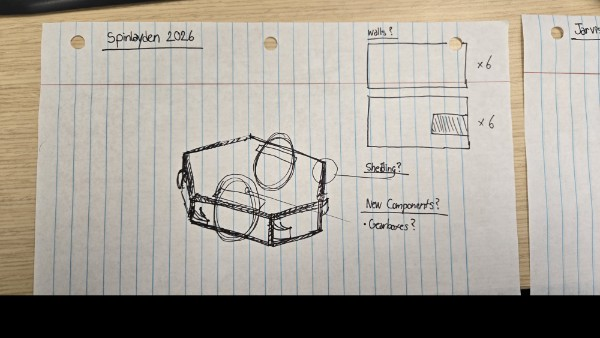
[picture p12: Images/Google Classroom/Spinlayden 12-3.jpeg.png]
Hand-drawn concept sketch of Spinlayden 2026 showing hexagonal chassis and design notes


### Design Motivation

Spinlayden's design is driven by the goal of delivering maximum damage while maintaining mobility and resilience. The 14" x 12" hexagonal chassis, crafted from 1/8" 6061 aluminum with cutouts on the inner half of the walls to reduce weight, allows us to spin at 645.6 RPM.

The Melty-Brain system, powered by two EZRUN 3660 SL G2 motors, combines high torque with precise control via Raspberry Pi 4B, running a C# program that utilizes the physics from the OpenMelt project on GitHub, allowing Spinlayden to spin as both a weapon and a shield, while still being able to move at the same time.

Six 1/2" carbon steel hex bolts are threaded through the outer walls of the chassis — one per face — to deliver impact damage (estimated 78J per rotation from the full spinning mass) without compromising the 15-lb weight limit.

### Research Methods

We started by analyzing previous AWT competitions and even other competitions/streams online. We analyzed the success, strengths, and weaknesses of our own bots and other teams.

### Refinement

Throughout the design process, Spinlayden 2.0 underwent several key refinements based on lessons learned from Spinlayden 1.0:

**Weight Reduction Redesign:** The original weight reduction holes weakened the chassis walls at stress points. For 2.0, we redesigned the cutout geometry to remove material only from the inner half of the walls, preserving structural integrity at the edges where impacts occur.

**Component Repositioning:** In 1.0, internal components (batteries, ESCs, Pi) were mounted too close to the outer walls, making them vulnerable to hits that deformed the chassis inward. The 2.0 layout moves components closer to the center of the bot.

**Weapon Redesign:** The original machined blade-style weapons were replaced entirely. Spinlayden 2.0 uses 1/2" carbon steel hex bolts threaded through the chassis walls — a simpler, more robust approach that delivers brute-force impact through the bolt tip and shank and allows for fast field replacement with standard hardware.

**Dedicated Raspberry Pi Housing:** The Pi was unprotected in 1.0, leaving the control system exposed. A dedicated 3D-printed housing now shields the Pi from impacts and vibration.

**Software Rewrite (Python → C#):** The original Python meltybrain software suffered from input lag due to Python's interpreted execution. The team rewrote the control system in C# for compiled performance and reduced latency.

**Controller Upgrade (Bluetooth → Analog RC):** The Bluetooth Xbox controller used in 1.0 experienced frequent connection drops during matches. We switched to a traditional analog RC car controller with a dedicated receiver for more reliable communication.

**Counterweight Removal:** The 1.0 design used counterweights to balance the spinning chassis, adding complexity and weight. The 2.0 design achieves balance through symmetric component placement, eliminating the need for dedicated counterweights.

**3D Printed Prototyping:** Before cutting metal, we 3D printed prototype wall sections and assemblies to verify fit, test component clearances, and catch design issues early.

### Risk Analysis

In addition to the component-level failure analysis (FMEA) below, the team identified project-level risks that could affect the schedule, manufacturing process, or competition outcome. The following risk matrix assesses each risk by severity and likelihood on a 1–10 scale and documents the mitigation strategy in place.

**Table 11:** Project-Level Risk Matrix

| Risk Category | Risk | Cause | Impact | Severity (1-10) | Likelihood (1-10) | Mitigation |
|---|---|---|---|---|---|---|
| Schedule | Documentation not completed by deadline | Large scope (35 rubric sections), limited time, 8 bios still pending | Incomplete submission reduces rubric score | 7 | 5 | Rubric compliance tracker created to prioritize high-impact sections; documentation work began early in the season; TODO items assigned to specific team members |
| Schedule | Testing not completed before competition | Robot assembly delays push testing window past April 24 | Bot enters competition without full-speed validation | 8 | 4 | Four-phase testing plan started April 14; critical tests (spin-up, drive, weapon) prioritized first; low-speed validation already complete |
| Manufacturing | Loss of machining access | External manufacturing partners (Monode, Case Western think[box]) become unavailable | Cannot fabricate precision chassis components | 9 | 3 | Relationships established early in season; backup CNC available (Lunyee 3018 Pro Ultra) for smaller parts; waterjet cutting completed ahead of schedule |
| Manufacturing | 3D-printed components fail under combat loads | PLA/PETG parts crack or deform from vibration or impact | Internal mounts or Pi housing break during match | 5 | 5 | 3D-printed parts used only for non-structural internal mounts; critical structural components machined from aluminum or steel; spare printed parts prepared in advance |
| Manufacturing | Parts arrive late or incorrect | Vendor shipping delays or ordering errors | Build schedule slips; team cannot assemble on time | 7 | 4 | Parts ordered early in the season; owned inventory from Spinlayden 1.0 covers critical drive and power components; budget includes margin for expedited replacements |
| Competition | Opponent exploits exposed wheels | Wheels extend slightly beyond chassis perimeter | Wheel damage disables drivetrain; bot cannot translate | 7 | 6 | BaneBots wheels are inexpensive and quick to replace between matches; spare wheels and gearboxes on hand; bot can still spin as a weapon even without drive |
| Competition | Match loss due to control errors | Operator inexperience with meltybrain driving or mode switching | Bot drives into walls, fails to engage, or wastes match time | 6 | 5 | Two-operator system splits driving and mode management; practice sessions scheduled during April testing window; operators trained on Spinlayden 1.0 last season |
| Competition | Battery depletion mid-match | High current draw from both drive motors at full spin | Bot loses power before 3-minute match ends | 8 | 3 | Four Liperior 3S 3200 mAh LiPo batteries available (included with the AWT RoboBots kit); battery endurance testing planned to confirm runtime exceeds match duration; fresh packs loaded before each match |
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

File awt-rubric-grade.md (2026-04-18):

# AWT 2026 Rubric Grade — main.md

Graded against the official AWT references in `AWT Interview & Documentation References-20260414T232350Z-3-001/`:

- `Documentation Scoring 2026 (10-20-2025).xlsx` — the scoresheet
- `Documentation Sections 2026.docx` — the list of required sections
- `Documentation Details.pdf` — the narrative guidance on what "high marks" look like
- `Example Documentation — Final Blue Streak of Death 2023-2024.pdf` — exemplar reference

## Rubric Model (2026 AWT)

17 criteria, each scored 0–4 (0 = not covered, 4 = superior content). **Max = 68 points.**

| Section | Items | Max |
|---|---|---|
| Design Motivation/Strategy | Influences | 4 |
| Team Procedures | Team Management, Material Management/BOM, Accounting/Budget, Time Management | 16 |
| Design Process | Materials Selection, Research Methods, CAD Models, Structural Analysis, Engineering Drawing Set, Weapon System, Drive System, Power System, Wiring Schematic, Manufacturing Plans/Assembly, Testing Results, Design Refinement | 48 |
| **Total** | | **68** |

American letter-grade conversion:

| % | Letter |
|---|---|
| 93–100 | A |
| 90–92 | A- |
| 87–89 | B+ |
| 83–86 | B |
| 80–82 | B- |
| 77–79 | C+ |
| 73–76 | C |
| 70–72 | C- |
| 67–69 | D+ |
| 63–66 | D |
| 60–62 | D- |
| <60 | F |

---

## Scores by Criterion

### Design Motivation / Strategy

| # | Criterion | Score | Evidence in main.md | Notes |
|---|---|---|---|---|
| 1 | Influences | **4/4** | Lines 243–282. Strengths/weaknesses of 1.0 (Table 1), 7-row Problem→Solution table (Table 2), three CAD/photo figures of Spinlayden 1.0, and an explicit "What Was Changed" list. | Exemplary — every 2.0 design choice traces back to a concrete 1.0 failure. |

**Subtotal: 4 / 4**
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

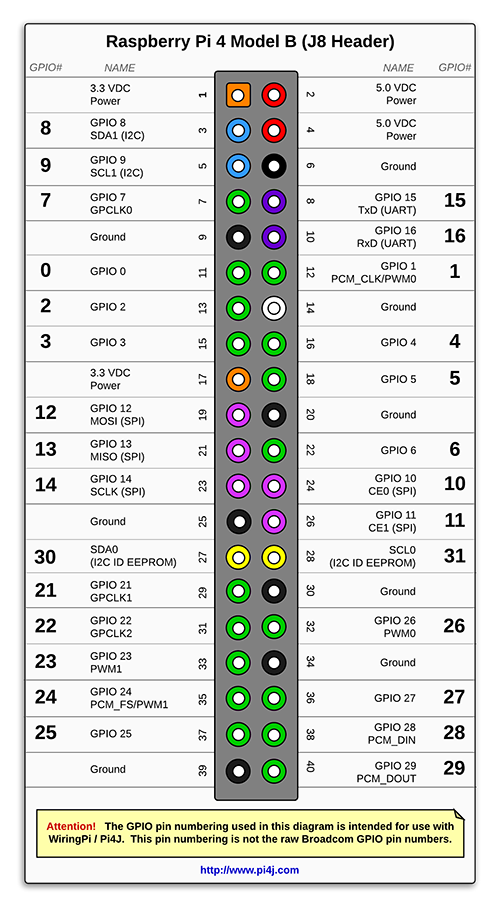
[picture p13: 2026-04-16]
Images/Discord/pi4j-rpi-4b-pinout-small.png

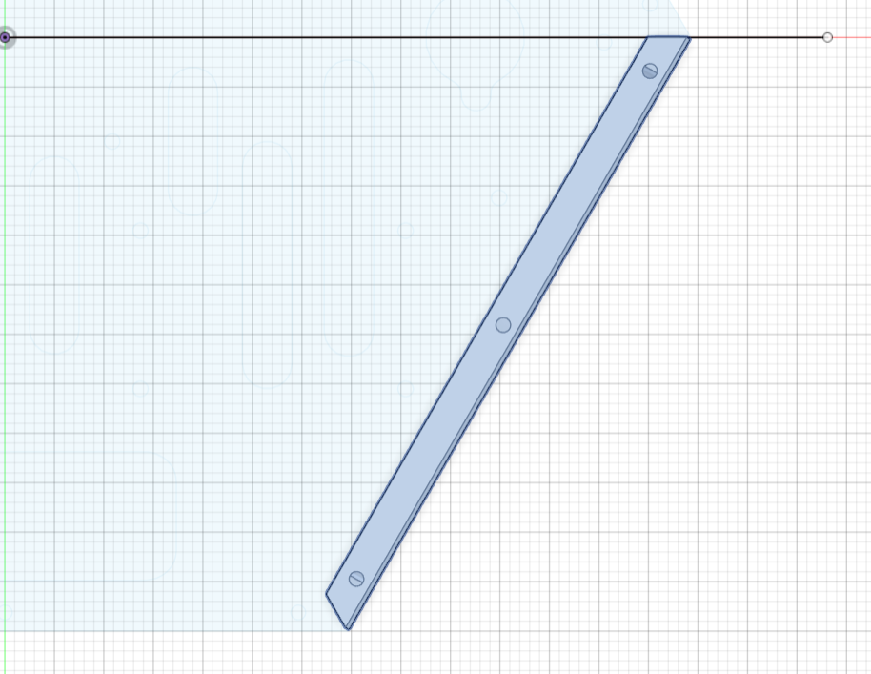
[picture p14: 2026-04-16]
Google Drive/Spinlayden-20260416T201050Z-3-001/Spinlayden/Spinlayden Machined Part Info/Primary Wall/Spinlayden Design-1.png

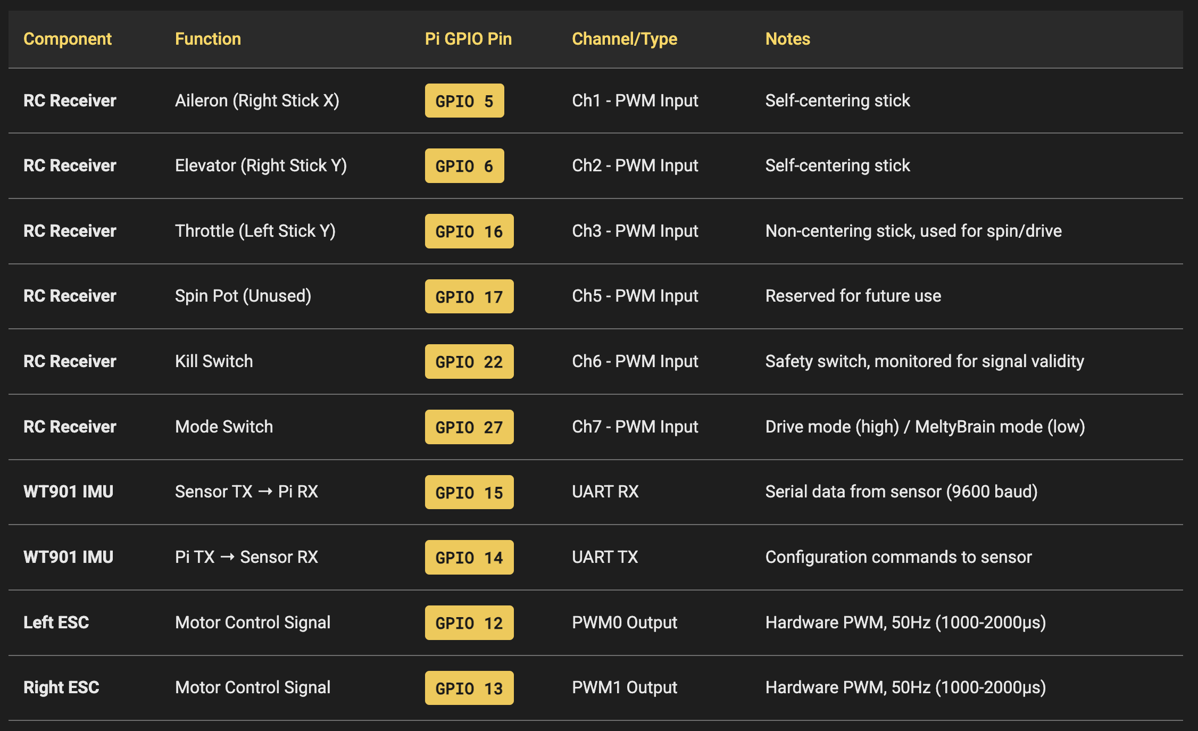
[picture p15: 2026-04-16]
Images/Discord/Screenshot_2026-03-03_at_2.26.50_PM.png

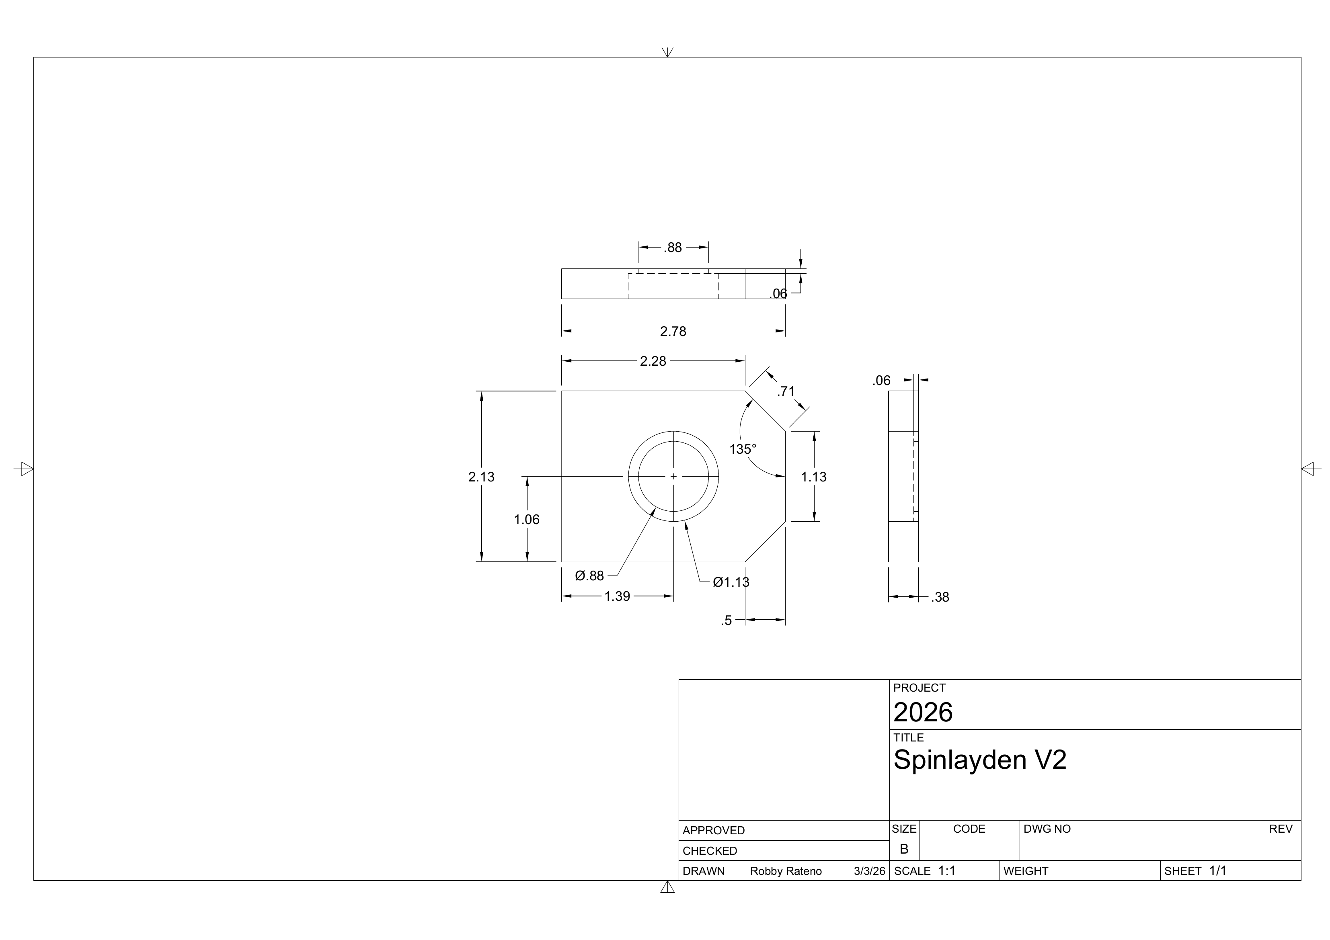
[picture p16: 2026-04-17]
Images/Engineering Drawings/Bearing_Mount_Drawing-2.png

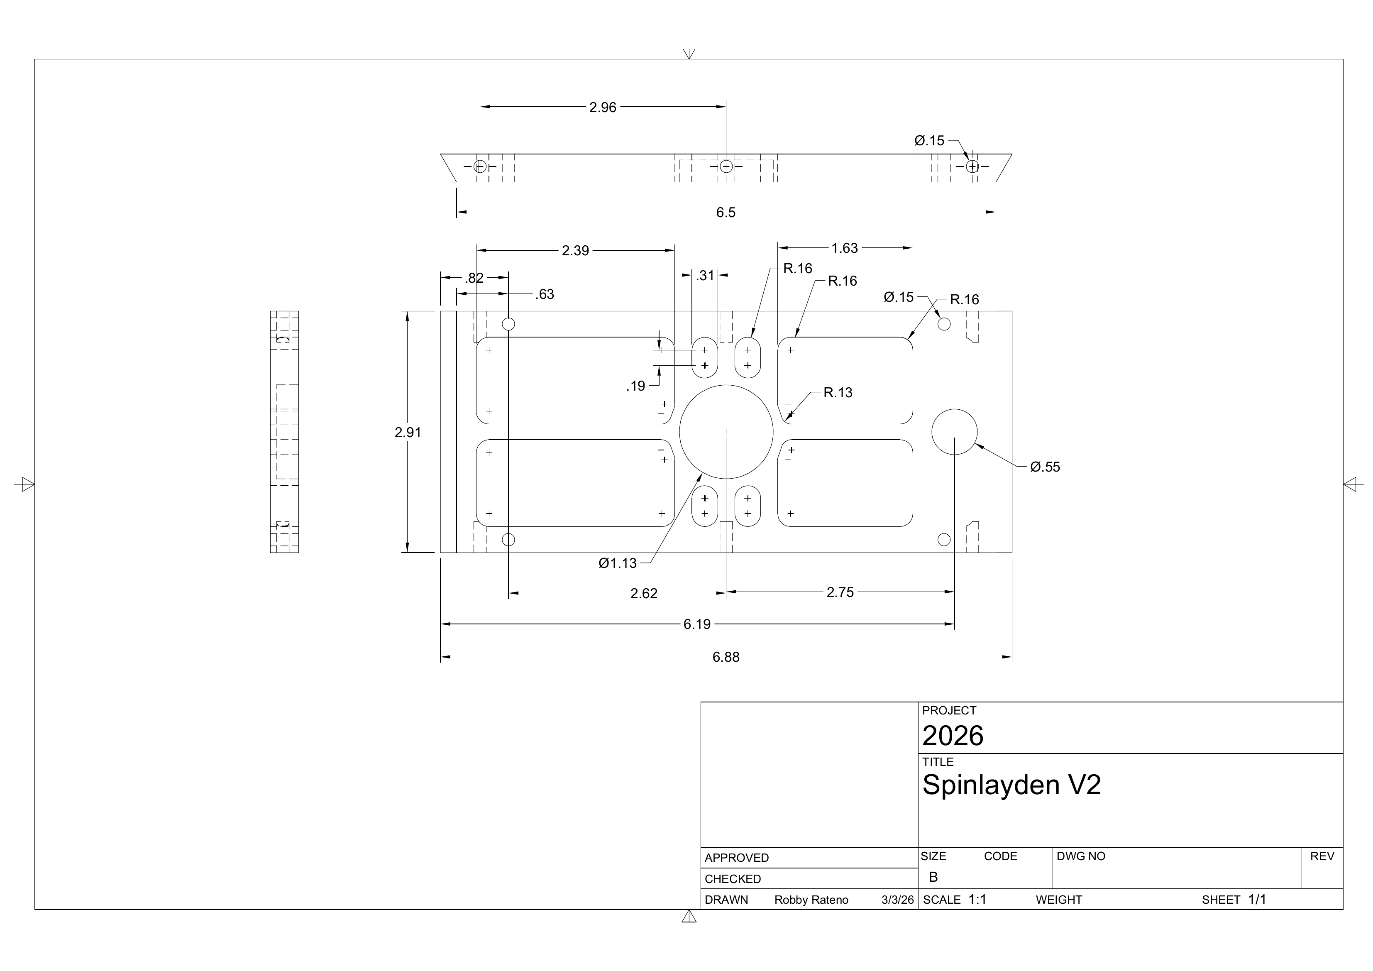
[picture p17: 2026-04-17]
Images/Engineering Drawings/Wall_Drawing-2.png

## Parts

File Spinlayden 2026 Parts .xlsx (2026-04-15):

Requested Buyer | Category | Part | Name | Link | Unit Price | # Owned | # Needed | Part # | # Total | Actual Price | New Expendetures (2025)
AWT | Chassis | Wall Metal | Multipurpose 6061 Aluminum Bar, 3/8" Thick x 8" Wide, 2 Feet Long | https://www.mcmaster.com/products/aluminum-plates/thickness~3-8-2/thickness~0-375/width~8/length~24/length~2-ft/ | $78.19 | 0 | 2 | 8975K372 | 2 | $156.38 | $156.38
AWT | Chassis | Plate Metal | Multipurpose 6061 Aluminum Sheet 1/8" Thick (29" x 25") | https://www.mcmaster.com/89015K319/ | $232.00 | 0 | 1 | 89015K319 | 1 | $232.00 | $232.00
AWT | Weapon | Blade Metal | Impact-Resistant A516 Carbon Steel, 6" x 6" x 1" | https://www.mcmaster.com/catalog/131/4219/89015K319steel~/shape~sheet-and-bar/thickness~1-000/thickness~1-3/impact-resistant-a516-carbon-steel/ | $208.35 | 0 | 1 | 1631T61 | 1 | $208.35 | $208.35
Riverside | Drive | Ball Bearing | (20) R8-2RS Sealed Ball Bearing 1/2"x1-1/8"x5/16" - Lubricated - Chrome Steel 20Pcs | https://www.amazon.com/R8-2RS-Sealed-Ball-Bearing-x1-1/dp/B0B3J1W6NZ?s=industrial | $12.99 | 0 | 1 |  | 1 | $12.99 | $12.99
Riverside | Brain | Rasberry Pi 4B | Rasberry Pi 4B 8gb RAM | Raspberry Pi 4 Model B 8GBAmazon.comhttps://www.amazon.com › Raspberry-Pi-4-4G-Model (https://www.amazon.com/Raspberry-Pi-4-4G-Model/dp/B081YD3VL5) | $97.99 | 0 | 2 | Microcenter | 2 | $195.98 | $195.98
Riverside | Power | Battery Connectors | (8) Xt60 Connector & Wire Covers | https://www.amazon.com/Wolfwhoop-XT60-Connector-Housing-Silicon/dp/B07C5J43ZL | $12.99 | 0 | 1 |  | 1 | $12.99 | $12.99
Riverside | Chassis | Thread Lock | Kraken Bond KH 62 Red Threadlocker | https://share.google/WEV3vj3xdpeda6Fa1 | $9.99 | 0 | 1 |  | 1 | $9.99 | $9.99
Riverside | Power, Brain | Solder | 63-37 Tin Lead Rosin Core Solder Wire for Electrical Soldering (0.8mm 100g) | https://www.amazon.com/gp/product/B0CHM5QS3N/ref=sw_img_1?smid=AKFL6YKYZULXS&th=1 | $11.99 | 0 | 1 |  | 1 | $11.99 | $11.99
Riverside | Brain | Wires | ELEGOO 120pcs Multicolored Dupont Wire | https://www.amazon.com/Elegoo-EL-CP-004-Multicolored-Breadboard-arduino/dp/B01EV70C78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 | $6.98 | 0 | 1 |  | 1 | $6.98 | $6.98
Riverside | Chassis | TPE Rubber Filament | eSUN Flexible TPE Filament 1.75mm, TPE-83A 3D Printer Filament | https://www.amazon.com/eSUN-Flexible-Filament-Printing-Printers/dp/B08RRWZRPQ | $28.11 | 0 | 1 |  | 1 | $28.11 | $28.11
Riverside | Chassis | PET G Plastic Filament | Official CR PETG 3D Printer Filament 1.75mm 1KG (2.2lbs) | https://www.amazon.com/Official-Creality-Precision-Toughness-Moistureproof/dp/B0C8NP63GD | $12.99 | 0 | 1 |  | 1 | $12.99 | $12.99
Riverside | Drive | 3" Shaft | Rotary Shaft, 1045 Carbon Steel, 3" | https://share.google/lZljnIYV1s7Qoj4nu | $9.25 | 0 | 4 | Found at https://www.mcmaster.com/products/rotary-shafts/shafts-2~/keyed-rotary-shafts-5/. 1/2" Dia. (Tolerance: -0.0025" to 0") 3" 0.125" key width 1/16" depth. 1497K7 | 4 | $37.00 | $37.00
Riverside | Drive | Pulley | Terre Products Heavy Duty 1.75" V-Groove Drive Pulley | https://share.google/xgnd6Wb7NK2x8JHfx | $16.92 | 0 | 6 |  | 6 | $101.52 | $101.52
Riverside | Drive | Belt | Dayco 4L160 Utility V-Belt | https://share.google/CJMUQI0gt8t5kmACn | $7.29 | 0 | 1 | Order 6, then 6 + shipping = 24.71 | 1 | $7.29 | $7.29
Riverside | Chassis | Top Plate Screws | (100) #10-24 x 3/8" Alloy Steel 10.9 Grade Hex Socket Button Head Cap Screws | Amazon.com: 10-24 x 3/8" Button Head Socket Cap Screw ...Amazon.comhttps://www.amazon.com › 10-24-Button-Socket-Screw... (https://www.amazon.com/10-24-Button-Socket-Screw-Thread/dp/B07NCKK4ZW) | $67.00 | 0 | 1 |  | 1 | $67.00 | $67.00
Riverside | Weapon | Weapon Screws | (50) #10-24 x 3/4 inch Flat Head Socket Cap Screws, Countersunk Head, Allen Hex Drive, 304 Stainless Steel 18-8 | https://www.amazon.com/Socket-Screws-Countersunk-Stainless-Machine/dp/B08DNTQ8WP | $7.98 | 0 | 1 |  | 1 | $7.98 | $7.98
Riverside | Saftey | Goggles | (12) Polycarbonate Protective Safety Glasses | https://www.amazon.com/YENPK-Glasses-Resistant-Sunglasses-Protection/dp/B0D9LSJSTF | $23.39 | 0 | 1 |  | 1 | $23.39 | $23.39
Riverside | Saftey | Gloves | (12) (Medium) ANSI A5 Polyurethane Coated Work Gloves | https://www.amazon.com/Griffin-Polyurethane-Coated-Gloves-Medium/dp/B085R3ST1X | $81.43 | 0 | 1 |  | 1 | $81.43 | $81.43
Riverside Robotics | Drive | Wheel Hub | T81 Hub, 1/2in Hex Shaft | https://banebots.com/t81-hub-1-2in-hex-shaft/ | $4.50 | 8 | 0 |  | 8 | $36.00 | $0.00
Riverside Robotics | Drive | Wheel | BaneBots Wheel | https://banebots.com/banebots-wheel-3-7-8-x-0-8-hub-mount-30a-green/ | $4.25 | 12 | 0 |  | 12 | $51.00 | $0.00
Riverside Robotics | Drive | Wheel | EZRUN 3660 SL G2 Motor | https://www.hobbywingdirect.com/products/ezrun-3660sl-g2-motors | $81.00 | 4 | 0 |  | 4 | $324.00 | $0.00
Riverside Robotics | Drive | Wheel | EZRUN MAX10 SCT | https://www.hobbywingdirect.com/products/ezrun-max10-sct | $119.00 | 4 | 0 |  | 4 | $476.00 | $0.00
Riverside Robotics | Drive | Wheel | (16) LANIAKEA Ball Bearing 5/8in | https://www.amazon.com/LANIAKEA-Transfer-Bearings-Transmission-Furniture/dp/B0895QYYSV | $16.99 | 1 | 0 |  | 1 | $16.99 | $0.00
Riverside Robotics | Power | Battery | Liperior 2700mAh 4S 30C 14.8V Lipo Battery with XT60 Plug for RC Plane / Heli | https://share.google/lvfP08Ir7iSB79n1B | $28.99 | 6 | 0 |  | 6 | $173.94 | $0.00
Riverside Robotics |  | Charger | MORE MORE MORE BATTERY CHARGER |  |  |  |  |  | 0 | $0.00 | $0.00
Riverside Robotics | Power | Battery | MORE MORE MORE MORE |  |  |  |  |  | 0 | $0.00 | $0.00
Riverside Robotics | Power | Killswitch | MS-05 Switch | https://teamwhyachi.com/product/ms-05-switch/ | $75.00 | 2 | 0 |  | 2 | $150.00 | $0.00
Advisors (Carbones) | Chassis, Weapon | CNC Mill | Lunyee 3018 Pro Ultra CNC Machine 500W All-Metal CNC | https://www.amazon.com/dp/B0CHM481NS?ref=ppx_yo2ov_dt_b_fed_asin_title&th=1 | $499.00 | 0 | 1 |  | 1 | $499.00 | $499.00
Advisors (Carbones) | Club | Shirts | Vistaprint Custom Team Shirts (2025) | https://www.vistaprint.com/oh/ | $23.91 | 0 | 10 |  | 10 | $239.09 | $239.09
Advisors (Carbones) | Drive | Gyro | WT901 High-Accuracy 3-axis Acceleration+Gyroscope+Tilt Angle +Magnetometer with Kalman Filtering, 9-axis MPU9250 USB 200Hz IMU Raspberry Pi AHRS Module | https://www.amazon.com/dp/B07GBRTB5K?ref=ppx_yo2ov_dt_b_fed_asin_title | $32.65 | 0 | 2 |  | 2 | $65.30 | $65.30
Advisors (Carbones) | Drive | Drill Bit Packs | Milwaukee Tool Hex Bits | https://www.homedepot.com/ | $8.55 | 0 | 4 |  | 4 | $34.20 | $34.20
Advisors (Carbones) | Chassis | Filament | PLA Filament | (student-sourced) | $20.00 | 0 | 1 |  | 1 | $20.00 | $20.00
Advisors (Carbones) | Drive | Wheel | P6S Gearbox: Standard Duty, 20:1 | https://banebots.com/p6s-54-s/ | $63.65 | 2 | 2 |  | 4 | $254.60 | $127.30
 |  |  |  |  |  |  |  |  | Riverside | $617.63 | $617.63
 |  |  |  |  |  |  |  |  | Advisors | $1112.19 | $984.89
 |  |  |  |  |  |  |  |  | Team | $1227.93 | $0.00
 |  |  |  |  |  |  |  |  | AWT | $596.73 | $596.73
 |  |  |  |  |  |  |  |  | Total | $3554.48 | $2199.25

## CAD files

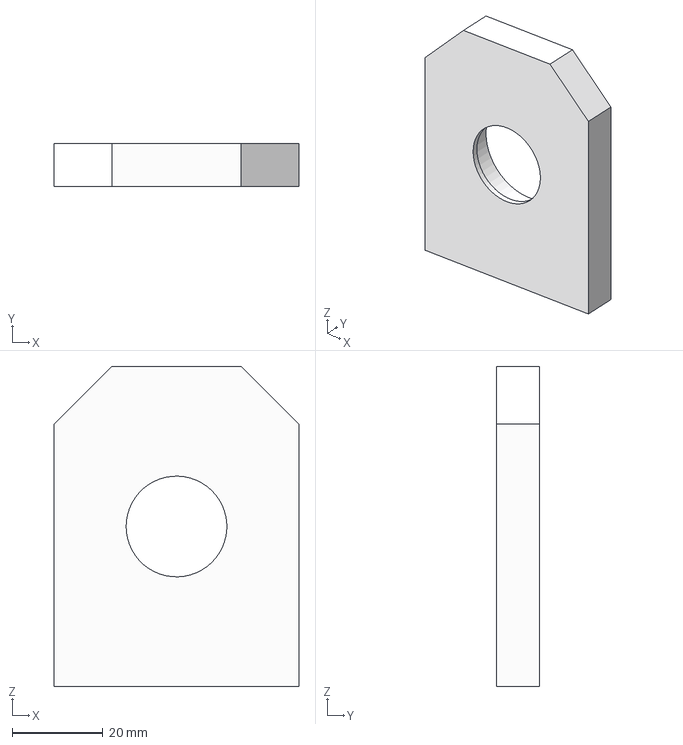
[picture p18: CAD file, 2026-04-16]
Google Drive/Spinlayden-20260416T201050Z-3-001/Spinlayden/Spinlayden Machined Part Info/Bearing Holder.step
54.0 x 9.53 x 70.6 mm

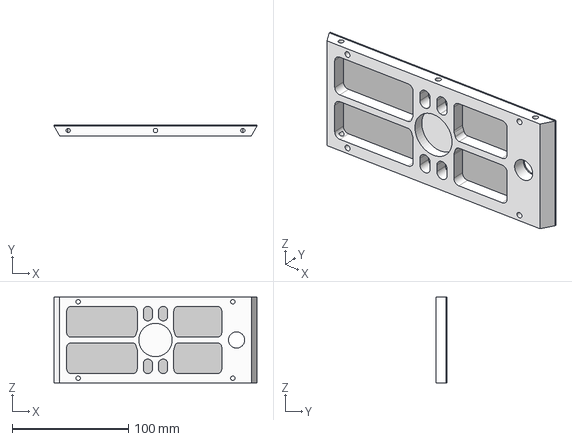
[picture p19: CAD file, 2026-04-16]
Google Drive/Spinlayden-20260416T201050Z-3-001/Spinlayden/Spinlayden Machined Part Info/Wall.step
174.9 x 9.53 x 73.8 mm
Steel Wall
Aluminum Frame

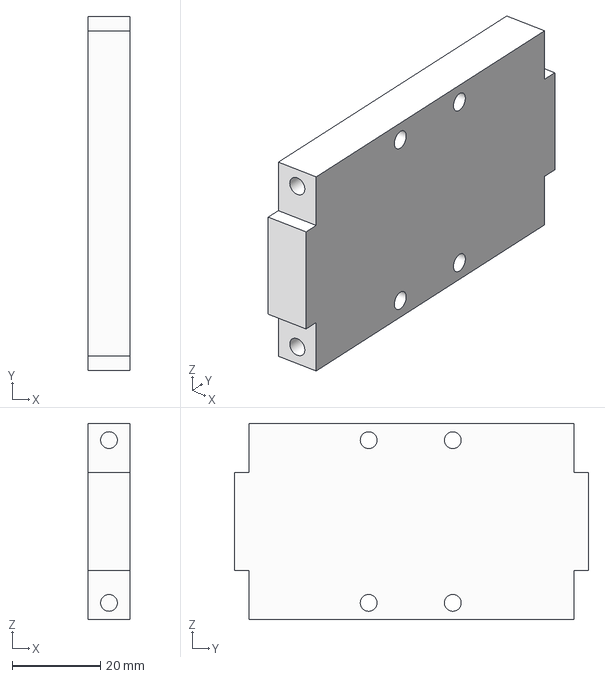
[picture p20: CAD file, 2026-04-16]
Google Drive/Spinlayden-20260416T201050Z-3-001/Spinlayden/Spinlayden Machined Part Info/GearBox Mount.step
9.53 x 80.1 x 44.5 mm

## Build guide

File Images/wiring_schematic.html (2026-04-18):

Spinlayden 2.0 — Wiring Schematic

Single MS-05 kill switch on the +V main trunk cuts power to every bot subsystem — both motors, Pi, receiver, IMU. GND is a continuous common return that bypasses the switch. FS-iA6B receiver connects to the Pi on 3 wires. Dual EZRUN MAX10 ESCs drive EZRUN 3660 SL G2 motors.

Power Path · high current · 11.1 V main bus (+V red / GND black)

Bank A (left packaging)

Bank B (right packaging)

Battery 1Liperior 3S LiPo3200 mAh

+−

Battery 2Liperior 3S LiPo3200 mAh

+−

Battery 3Liperior 3S LiPo3200 mAh

+−

Battery 4Liperior 3S LiPo3200 mAh

+−

+V bus · 11.1 V trunk (~12,800 mAh)

GND bus · common return (bypasses kill switch)

MS-05 KILL SWITCH single · on +V trunk · cuts ALL bot power when thrown both ESCs, Pi, receiver, IMU all go dark in one action

+V splits to both ESCs →

GND splits to both ESCs →

Left ESC EZRUN MAX10 SCT · 120 A continuous 3-phase output → Left motor BEC +5 V → Pi Pin 4 (powers Pi)

Right ESC EZRUN MAX10 SCT · 120 A continuous 3-phase output → Right motor BEC +V: NOT CONNECTED

Left Motor Hobbywing EZRUN 3660 SL G2 brushless · 20:1 gearbox

Right Motor Hobbywing EZRUN 3660 SL G2 brushless · 20:1 gearbox

Signal Path · low current · 2.4 GHz radio · GPIO · UART

FlySky FS-i6X 2.4 GHz transmitter (operator, outside bot)

2.4 GHz air link →

FS-iA6B receiver iBUS out — 3 wires total V+ · GND · S (signal) 115200 baud → UART3 RX on Pi

Raspberry Pi 4B (8 GB) C# meltybrain control · GPIO header (J8) Pin 2 (5V) ◄ FS-iA6B V+ Pin 6 (GND) ◄ FS-iA6B G Pin 29 (GPIO 5, UART3 RX) ◄ FS-iA6B iBUS S Pin 4 (5V) ◄ Left ESC BEC +5 V (powers Pi) Pin 32 (GPIO 12, PWM0) ► Left ESC signal in Pin 33 (GPIO 13, PWM1) ► Right ESC signal in Pin 1 (3V3) ► IMU VCC Pin 8 (GPIO 14, UART0 TX) ► IMU RX Pin 10 (GPIO 15, UART0 RX) ◄ IMU TX Pin 9 / 14 / 20 (GND) ► IMU, Left ESC, Right ESC GND

WT901 / WT61P IMU 9-axis gyroscope · 200 Hz 4-wire tie — VCC · TX · RX · GND UART0 · 9600 baud 3.3 V rail from Pi Pin 1

#### Legend

+V high-current power (batteries → kill switch → ESCs → motors)

GND common return (batteries → around kill switch → ESCs)

BEC +5 V (Left ESC → Pi Pin 4; regulated, dashed)

Receiver iBUS signal (UART3, 115200 baud)

PWM (50 Hz, 1–2 ms) — Pi → ESCs

IMU UART (TX/RX) — Pi ↔ WT901 at 9600 baud

#### Kill-switch behavior

The MS-05 sits on the +V rail of the 11.1 V main trunk upstream of the ESC split. GND is a common return that bypasses the switch entirely. Throwing the switch cuts current to both ESCs, which also cuts the Left-ESC BEC that powers the Pi — every active subsystem (motors, Pi, receiver, IMU) drops in one action. Satisfies AWT 2.4 (full deactivation within 60 s via manual disconnect).

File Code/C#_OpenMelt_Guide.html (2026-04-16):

# Spinlayden MeltyBrain Combat Robot

A dual-mode spinning combat robot with RC control, IMU sensing, and phase-aligned motor control

info Overview Step 1: RC Input Step 2: Sensors Step 3: Heading Step 4: Safety Step 5: Modes Step 6: Motors settings Technical

rocket_launch

## What is Spinlayden?

Spinlayden is a combat robot built for competitions like BattleBots. What makes it special? It can spin its entire body like a top while still moving in any direction you want! This is called a "MeltyBrain" robot.

Think about it: when something is spinning really fast, how do you make it move left or right? That's the challenge we're solving! The robot uses a Raspberry Pi computer running at 100 times per second to figure out exactly when to pulse the motors to create movement.

### Two Operating Modes

#### directions_car Drive Mode

Simple forward-only driving, like a car. Use the left stick to go forward, right stick to steer left/right. This is the safe starting mode when you first power on.

#### psychology MeltyBrain Mode

Full-body spinning! The robot spins like a top, but you can still control which direction it moves using the right stick. Left stick controls how fast it spins.

### The Control Loop (100 times per second!)

Here's what happens every 0.01 seconds (that's 10 milliseconds, or 1/100th of a second):

1

Read RC Controller — What are the sticks doing? Is the kill switch on?

2

Read Sensors — Which direction is the robot facing? How fast is it spinning?

3

Calculate True Heading — Combine gyroscope (fast) with compass (accurate) to know exactly which way we're pointing

4

Check Safety — Is the kill switch active? Which mode are we in?

5

Calculate Motor Powers — Based on the mode, figure out how much power each wheel needs

6

Send to Motors — Tell the ESCs (motor controllers) what to do

#### Key Technologies

C# Programming Raspberry Pi IMU Sensors PWM Signals Real-Time Control

1

## Reading the RC Controller

Your RC transmitter (the controller) sends signals to a receiver on the robot. The receiver outputs these as PWM pulses on different channels. Think of PWM like a light switch that turns on and off really fast - the longer it's "on", the higher the value.

### What is PWM?

PWM = Pulse Width Modulation. Imagine you have a light switch that turns on and off 50 times per second. If it's on for 1 millisecond (1ms), that's 0%. If it's on for 2ms, that's 100%. If it's on for 1.5ms, that's 50%.

RC receivers work the same way: they send pulses between 1000µs (1ms) and 2000µs (2ms). The Raspberry Pi measures how long each pulse is to figure out where your sticks are.

### The 6 Channels We're Reading

Channel | GPIO Pin | What It Controls | Output Range
Ch1 | GPIO 5 | Right Stick Left/Right | -1.0 (left) to +1.0 (right), 0 = center
Ch2 | GPIO 6 | Right Stick Up/Down | -1.0 (down) to +1.0 (up), 0 = center
Ch3 | GPIO 16 | Left Stick Up/Down (Throttle) | 0.0 (bottom) to 1.0 (top)
Ch5 | GPIO 17 | (Not Used) | 0.0 to 1.0
Ch6 | GPIO 22 | Kill Switch (Safety) | 0.0 (off) or 1.0 (on)
Ch7 | GPIO 27 | Mode Switch | 0.0 (MeltyBrain) or 1.0 (Drive)

### How We Measure the Pulses (Edge Detection)

The Raspberry Pi can detect when a GPIO pin goes from LOW (0 volts) to HIGH (3.3 volts) and vice versa. These are called edges:

- Rising Edge: Signal goes from LOW → HIGH (start of pulse)
- Falling Edge: Signal goes from HIGH → LOW (end of pulse)

We record the time at the rising edge, then calculate the difference at the falling edge. That's the pulse width!

code GpioRcInputReader.cs - Measuring Pulse Width

// This function is called every time a GPIO pin changes (rises or falls)
private void OnPinValueChanged(int channelIndex, PinValueChangedEventArgs args)
{
    // Get the current timestamp
    var now = Stopwatch.GetTimestamp();

    if (args.ChangeType == PinEventTypes.Rising)
    {
        // Rising edge: Record when the pulse started
        _risingTimestamps[channelIndex] = now;
    }
    else
    {
        // Falling edge: Calculate how long the pulse was
        long risingTime = _risingTimestamps[channelIndex];

        // Convert from CPU ticks to microseconds (µs)
        float elapsedUs = (float)(now - risingTime) * 1_000_000f / Stopwatch.Frequency;

        // Smooth the value using EMA (Exponential Moving Average)
        // This removes jitter/noise from the measurements
        float alpha = SmoothingAlpha[channelIndex];
        _pulseWidthsUs[channelIndex] =
            _pulseWidthsUs[channelIndex] * (1 - alpha) + elapsedUs * alpha;

        // Track the kill switch to know if RC signal is alive
        if (channelIndex == 4) // Channel 6 (index 4)
            _lastKillSwitchPulseTimestamp = now;
    }
}

#### warning Safety Check: Signal Validity

If we don't receive a pulse on the kill switch channel for more than 100 milliseconds, we assume the RC signal is lost (maybe you walked too far away, or batteries died). The robot immediately stops all motors for safety!

2

## Reading the IMU Sensor (WT901)

IMU = Inertial Measurement Unit. It's like the motion sensor in your phone that knows when you tilt or rotate it. Our WT901 sensor has three types of sensors built in:

- Accelerometer: Measures acceleration (like feeling yourself pushed back in a car)
- Gyroscope: Measures rotation speed (how fast you're spinning)
- Magnetometer: Measures magnetic field (like a compass) - we turn this OFF because motors create magnetic interference

### Why Do We Need Sensors?

For MeltyBrain mode to work, we need to know exactly which direction the robot is facing at all times while it's spinning. If we don't know the heading, we can't time the motor pulses correctly, and the robot just spins in place instead of moving!

### How the Sensor Talks to the Pi (UART Serial)

The WT901 sensor sends data over a serial connection at 9600 baud (9600 bits per second). It sends small packets of data:

- Packet Type 0x51: Acceleration data (ax, ay, az)
- Packet Type 0x52: Angular velocity data (how fast it's spinning in each direction)
- Packet Type 0x53: Angle data (roll, pitch, yaw - which direction it's facing)

### Configuring for High-Speed Spinning

When we start up, we send special commands to configure the sensor for a spinning robot:

code Wt901SensorReader.cs - Sensor Configuration

// Configure WT901 for spinning platform
byte[] unlock    = [0xFF, 0xAA, 0x69, 0x88, 0xB5]; // Unlock configuration
byte[] axis6     = [0xFF, 0xAA, 0x24, 0x01, 0x00]; // Use 6-axis mode (no magnetometer)
byte[] filtk     = [0xFF, 0xAA, 0x25, 0x05, 0x00]; // Less smoothing = faster response
byte[] bandwidth = [0xFF, 0xAA, 0x1F, 0x00, 0x00]; // Maximum bandwidth (256 Hz)
byte[] save      = [0xFF, 0xAA, 0x00, 0x00, 0x00]; // Save settings

// Send each command with a small delay between them
_serialPort.Write(unlock,    0, 5); Thread.Sleep(10);
_serialPort.Write(axis6,     0, 5); Thread.Sleep(10);
_serialPort.Write(filtk,     0, 5); Thread.Sleep(10);
_serialPort.Write(bandwidth, 0, 5); Thread.Sleep(10);
_serialPort.Write(save,      0, 5);

#### Why 6-Axis Mode?

The magnetometer (compass) gets confused by the motors' magnetic fields. In 6-axis mode, the sensor only uses the gyroscope and accelerometer, which are more accurate for a spinning robot. The tradeoff? It can drift over long periods, so we use a complementary filter in Step 3 to fix that!

3

## Calculating True Heading (Complementary Filter)

We have two ways to know which direction the robot is facing, but each has problems:

- Gyroscope: Super fast and accurate for short periods, but slowly "drifts" over time (errors add up)
- AHRS (Attitude Heading Reference System): Slow to respond but doesn't drift over time

A complementary filter combines both! It uses the gyroscope for fast response and the AHRS to slowly correct any drift.

### How It Works (Every 10ms)

1. Integrate the gyroscope: Add (angular velocity × time) to our heading estimate
2. Calculate error: How different is our estimate from what the AHRS says?
3. Blend in correction: Add a tiny bit (0.2%) of that error back to slowly fix drift
4. Wrap angles: Keep everything between -180° and +180°

code BrainControlLoop.cs - Complementary Filter

// Step 1: Integrate gyroscope (fast, responsive)
// LoopDt = 0.01 seconds (our loop runs 100 times per second)
_lastHeading += sensorData.CurrentSpin * LoopDt;

// Step 2: Calculate error from AHRS
float ahrsError = sensorData.Heading - _lastHeading;

// Step 3: Handle angle wrap-around
// If error is > 180°, we went the "wrong way" around the circle
if (ahrsError >  180f) ahrsError -= 360f;
if (ahrsError < -180f) ahrsError += 360f;

// Step 4: Blend 0.2% of AHRS error for drift correction
// AhrsCorrAlpha = 0.002 (that's 0.2%)
_lastHeading += ahrsError * AhrsCorrAlpha;

// Step 5: Wrap heading to -180° to +180°
if (_lastHeading >  180f) _lastHeading -= 360f;
if (_lastHeading < -180f) _lastHeading += 360f;

#### Example: Why This Works

Imagine you're spinning and your gyro says you're at 45°, but AHRS says you're at 47°. There's a 2° error. Instead of instantly jumping to 47° (which would be jerky), we add 0.2% of that 2° error = 0.004°.

Over 500 loops, that 0.004° adds up to fix the full 2° drift, but it's so gradual you don't notice! Meanwhile, the gyro keeps giving us super fast, smooth updates every 10ms.

4

## Safety Interlock System

Before we do ANYTHING with the motors, we check two critical things:

1. Is the kill switch ON? If not, motors stay off no matter what.
2. Is the RC signal valid? If we lost connection, motors stay off.

We also use this step to determine which drive mode we're in based on the mode switch position.

code SafetyInterlock.cs - Safety Check

public SafetyState Evaluate(RcInputData rcInput)
{
    // Kill if RC signal is lost OR kill switch is off
    // Kill switch must be >= 0.8 (pretty close to 1.0) to be considered "on"
    bool isKilled = !rcInput.IsSignalValid || rcInput.KillSwitch < 0.8f;

    // Mode switch: >= 0.5 = Drive mode, < 0.5 = MeltyBrain mode
    var mode = rcInput.ModeSwitch >= 0.5f
        ? DriveMode.Drive
        : DriveMode.MeltyBrain;

    // Log when state changes (for debugging)
    if (isKilled && !_wasKilled)
        _logger.LogDebug("Kill switch ON — motors disabled");
    else if (!isKilled && _wasKilled)
        _logger.LogDebug("Kill switch OFF — armed in {Mode} mode", mode);

    _wasKilled = isKilled;
    return new SafetyState(isKilled, mode, DateTimeOffset.UtcNow);
}

#### warning Multiple Layers of Safety

- Robot always starts in killed state when powered on
- Default mode is Drive (safer than MeltyBrain)
- If RC signal is lost for >100ms, immediate emergency stop
- Kill switch must be firmly "on" (>0.8) to arm motors
- You can switch modes while killed (safe to test before arming)

5

## Calculating Motor Commands

Based on which mode we're in, we calculate how much power to send to the left and right motors. The two modes work completely differently!

### directions_car Drive Mode

Drive mode is simple: it's like driving a car or tank. Left stick up/down controls speed, right stick left/right controls steering.

- Left Stick Y: Forward throttle (0.0 = stopped, 1.0 = full speed forward)
- Right Stick X: Steering (-1.0 = turn left, +1.0 = turn right)

How steering works: When you turn right, the left wheel speeds up and right wheel slows down (differential drive). This makes the robot turn!

code BrainControlLoop.cs - Drive Mode

// Map throttle stick (0.0-1.0) to ESC range (0.5-1.0)
// ESCs treat 0.5 as "stopped" and 1.0 as "full forward"
float baseThrottle = rcInput.Throttle * 0.5f + 0.5f;
float steer = rcInput.Aileron;  // -1.0 to +1.0

// Differential drive: steer right → left wheel goes faster
float leftPower  = Math.Clamp(baseThrottle + steer * 0.5f, 0f, 1f);
float rightPower = Math.Clamp(baseThrottle - steer * 0.5f, 0f, 1f);

#### Example Calculation

Situation: Throttle at 50%, steering full right
baseThrottle = 0.5 * 0.5 + 0.5 = 0.75 (halfway between stopped and full)
steer = +1.0 (full right)
leftPower = 0.75 + (1.0 * 0.5) = 1.25 → clamped to 1.0 (full speed!)
rightPower = 0.75 - (1.0 * 0.5) = 0.25 (slow)
Result: Robot turns right while moving forward!

### psychology MeltyBrain Mode

This is where it gets cool! The entire robot is spinning like a top. To make it move in a direction while spinning, we pulse the motors at specific moments based on where the robot is pointing.

- Right Stick X/Y: Which direction you want to move
- Left Stick Y: How fast to spin (0.0 = no spin, 1.0 = max spin)

#### The Key Insight: Phase-Aligned Control

Imagine the robot is spinning clockwise and you want it to move to the right:

1. When the robot points right (your target), give motors more power
2. When the robot points left (opposite), give motors less power
3. When the robot points up or down (90° off), give motors normal power

Over one full rotation, the robot pushes harder in the right direction than any other direction. The net result? It moves right while spinning!

code TranslationEngine.cs - MeltyBrain Logic

// Calculate which direction the pilot wants to go from stick position
var stickMagnitude = new Vector2(
    pilotCommand.TranslationX,
    pilotCommand.TranslationY
).Length();

// Calculate target heading from stick direction
if (stickMagnitude > 0.01f)
{
    targetHeading = MathF.Atan2(
        pilotCommand.TranslationY,
        pilotCommand.TranslationX
    );
}

// Convert robot's current heading from degrees to radians
float headingRad = sensorData.Heading * MathF.PI / 180f;

// Calculate heading error (how far off are we from target?)
float headingError = NormalizeAngle(headingRad - targetHeading);

// Use cosine to create sinusoidal modulation:
//   cos(0°) = +1   → max forward when pointing at target
//   cos(90°) = 0   → no correction when perpendicular
//   cos(180°) = -1 → max reverse when pointing away
float correction = stickMagnitude * 0.8f * MathF.Cos(headingError);

// Add/subtract correction from base spin speed
float leftPower  = spinSpeed + correction;
float rightPower = spinSpeed - correction;

#### Why Cosine?

The cosine function gives us exactly what we need! When the error is 0° (pointing at target), cos(0°) = 1 (maximum correction). When error is 90° (perpendicular), cos(90°) = 0 (no correction). When error is 180° (opposite direction), cos(180°) = -1 (reverse correction). This creates a smooth sine wave of motor power as the robot spins!

6

## Sending Signals to the Motors (ESCs)

ESC = Electronic Speed Controller. Think of it like a smart power adapter for the motor. You tell it what speed you want (via a signal), and it controls the power going to the motor.

### Speaking the ESC's Language: PWM Signals

ESCs understand the same RC servo protocol we talked about in Step 1! They expect a 50Hz signal (50 pulses per second) where the pulse width tells them what to do:

Pulse Width | Power Value | Motor Response
1000µs (1ms) | 0.0 | Full Reverse (or stopped if ESC doesn't support reverse)
1500µs (1.5ms) | 0.5 | Neutral (stopped)
2000µs (2ms) | 1.0 | Full Forward

### Using Hardware PWM

The Raspberry Pi has hardware PWM, which means a dedicated chip generates these pulses with perfect timing. This is much better than software PWM (which can be jerky or inaccurate).

We configure two PWM channels in /boot/firmware/config.txt:

dtoverlay=pwm-2chan,pin=12,func=4,pin2=13,func2=4

This sets up:

- GPIO 12: PWM channel 0 (left motor)
- GPIO 13: PWM channel 1 (right motor)

### Converting Power to PWM Duty Cycle

The C# PWM library uses duty cycle (0.0 to 1.0) instead of pulse widths. Duty cycle is "what percentage of the time is the signal HIGH?"

Our PWM period is 20ms (50Hz). So:

- 1000µs out of 20000µs = 0.05 (5% duty cycle)
- 1500µs out of 20000µs = 0.075 (7.5% duty cycle)
- 2000µs out of 20000µs = 0.10 (10% duty cycle)

code MotorController.cs - Converting to PWM

private static double PowerToDutyCycle(float power)
{
    // Clamp power to 0.0-1.0 range (our ESCs can't go reverse)
    var clamped = Math.Clamp(power, 0f, 1f);

    // Map 0.0-1.0 power to 0.05-0.10 duty cycle
    // Formula: minDuty + (power * (maxDuty - minDuty))
    return 0.05 + (clamped * 0.05);
}

public Task SendCommandAsync(MotorCommand command, CancellationToken ct)
{
    // Convert both motor powers to duty cycles
    var leftDuty = PowerToDutyCycle(command.LeftWheelPower);
    var rightDuty = PowerToDutyCycle(command.RightWheelPower);

    // Set the hardware PWM duty cycles - happens instantly!
    _leftEsc!.DutyCycle = leftDuty;
    _rightEsc!.DutyCycle = rightDuty;

    return Task.CompletedTask;
}

#### Why Hardware PWM is Amazing

Once we set the duty cycle, the hardware chip keeps generating perfect pulses in the background. Even if our program gets busy doing calculations, the PWM signals stay perfectly timed at 50Hz. ESCs are very picky about timing, so this is crucial for smooth, reliable motor control!

terminal

## Technical Details & Setup

### Software Stack

- .NET 10 - Microsoft's latest cross-platform framework
- C# 13 - Modern programming language with advanced features
- System.Device.Gpio - Library for GPIO and PWM hardware access
- System.IO.Ports - Library for serial communication with sensors
- Dependency Injection - Clean architecture pattern for organizing code

### Project Structure

Spinlayden.Brain/
├── Program.cs                          // Starting point of the program
├── Infrastructure/
│   ├── BrainControlLoop.cs             // The 100Hz control loop
│   └── ServiceCollectionExtensions.cs  // Dependency injection setup
└── Features/
    ├── RcInput/
    │   └── GpioRcInputReader.cs        // Reads RC controller signals
    ├── SafetyInterlock/
    │   └── SafetyInterlock.cs          // Kill switch & mode logic
    ├── SensorReading/
    │   └── Wt901SensorReader.cs        // Reads IMU sensor data
    ├── Translation/
    │   └── TranslationEngine.cs        // MeltyBrain phase control math
    └── MotorControl/
        └── MotorController.cs          // Sends PWM to ESCs

### Deploying to the Raspberry Pi

To run this on the robot, you need to compile it for the Raspberry Pi's processor (ARM64) and copy it over:

# On your computer (Windows/Mac/Linux)
dotnet publish -c Release -r linux-arm64 --self-contained

# Copy to Raspberry Pi using SSH
scp -r bin/Release/net10.0/linux-arm64/publish/* pi@raspberrypi:~/spinlayden/

# On the Raspberry Pi, run with sudo (needed for GPIO access)
cd ~/spinlayden
sudo ./Spinlayden.Brain

### Tuning Parameters

These are constants in the code you can adjust to change the robot's behavior. Be careful - test small changes one at a time!

#### BrainControlLoop.cs

Parameter | Value | What It Does
LoopFrequencyHz | 100 | How many times per second the control loop runs
SpinQuantizeStep | 0.05 | Snap spin speed to 5% increments (prevents jitter)
SpinRampPerTick | 0.01 | How fast spin speed changes (1%/tick = 1 second to full)
AhrsCorrAlpha | 0.002 | How much AHRS correction to blend in (0.2% per tick)

#### TranslationEngine.cs

Parameter | Value | What It Does
TranslationGain | 0.8 | How aggressive translation is (higher = more responsive)
MaxWheelPower | 1.0 | Maximum motor power limit (safety)

#### GpioRcInputReader.cs

Parameter | Value | What It Does
StickAlpha | 0.3 | Smoothing for stick inputs (lower = smoother but slower)
PotAlpha | 0.05 | Heavy smoothing for throttle stick
SignalTimeoutTicks | 100ms | How long before declaring RC signal lost

school

## Want to Learn More?

This robot combines control systems, sensor fusion, real-time programming, and physics! Great topics to explore: PID controllers, Kalman filters, embedded systems, and robotics.

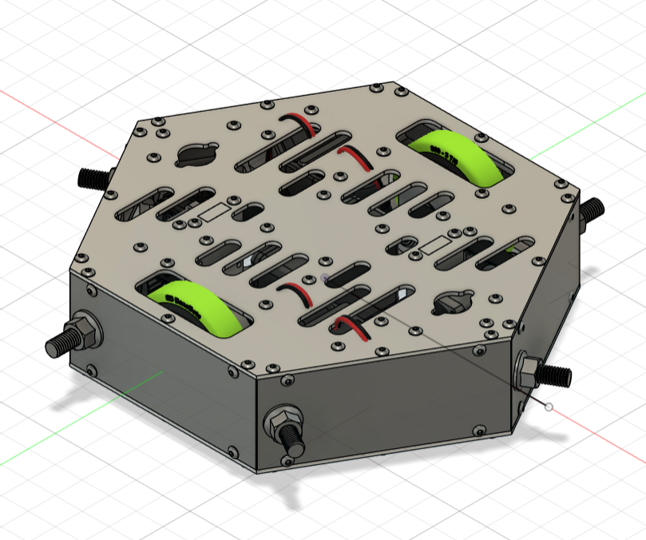
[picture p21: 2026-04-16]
Images/Spinlayden_2.0_Assembly_Silver.png

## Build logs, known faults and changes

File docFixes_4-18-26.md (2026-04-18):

# Documentation Fixes — 4-18-26

Consolidated list of everything `main.md` still needs before submission, pulled from the three independent grader reports in `grading/` (scores: 79/92, 72/96, 85/112 — consensus ~B, ~79%).

All three graders agreed on the same five gaps. Ordered by point impact.

---

## 1. Testing Results — highest impact

Currently written as "planned." Needs measured numbers.

Collect and paste into the Testing Results section:

- [ ] **Full-speed RPM** — tip / chassis RPM at full throttle (tachometer, high-speed-video frame count, or ESC telemetry)
- [ ] **Runtime** — minutes on a full battery pack at spin-up / idle
- [ ] **Impact test** — weapon bolt strike on a test target; note damage to target and any bot-side failures
- [ ] **Drive test** — translate-while-spinning meltybrain behavior; note drift or control issues
- [ ] **Date** each test was run and **who** ran it
- [ ] Photos or frame grabs of each test

Video of any test run is enough — I can pull frame-count RPM from it.

---

## 2. Promotional / Fundraising section — missing entirely

Add a new section under Project Overview. Cover:

- [ ] Team shirts / apparel (already in the BOM as a line item — call it out here as promo spend)
- [ ] Any social-media presence (Instagram, TikTok, etc.) or demo-day appearances
- [ ] Sponsor outreach: how Monode / Arc Technology / Show Studio were approached
- [ ] Fundraising totals and how funds were used
- [ ] Photos of the team in shirts or at an event

---

## 3. Manufacturing Plans / Assembly Procedure — missing

Add a step-by-step assembly procedure section. Cover:

- [ ] Order of assembly (chassis walls → gearbox mounts → motors → bearings → top plate → electronics)
- [ ] Tools required at each step
- [ ] Torque specs for the impact-weapon bolts and chassis fasteners
- [ ] Calibration / commissioning steps (IMU zeroing, ESC arming, meltybrain calibration)
- [ ] Photos of the partially-assembled bot at 2–3 stages

---

## 4. Meeting Minutes — pull into main.md

Currently only in `meetingNotes.md`. Judges want them in the main document.

- [x] Copy a summarized minutes table (date, attendees, topics, decisions) into `main.md` under Team Procedures or Time Management
- [x] Keep it tight — table format, not transcripts
- [x] Cross-reference `meetingNotes.md` for the long form

---

## 5. Wiring Schematic — needs to be a diagram

Currently a bulleted list. Judges want a real schematic.

- [ ] Draw a wiring diagram: battery → kill switch → BEC → Pi → ESCs → motors, plus IMU and receiver
- [ ] Fusion 360 Electronics, KiCad, or even a hand drawing photographed cleanly is acceptable
- [ ] Include fuse / kill-switch callouts (safety judges look for this)

---

## Smaller drawing fixes — ASME compliance

Our engineering drawings (`Images/Engineering Drawings/*.pdf`) use ASME Y14.5, inch units, ANSI B-size (11×17). Two gaps:

- [ ] Add a **third-angle projection symbol** to the title block on each drawing
- [ ] Add an **"UNLESS OTHERWISE SPECIFIED: ±.01"** tolerance note (or whatever tolerance the team is holding)
- [ ] Any new drawing: match the existing ASME style + ANSI B-size

---

## Deadline

Competition: April 25, 2026. Submission window closes before that.

Testing Results (#1) is the single highest-leverage fix — all three graders flagged it, and Grader 1 estimated it alone swings us from B+ to A.

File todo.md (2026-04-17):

# Documentation TODO List

---

## Missing Sections Required by AWT Rubric

These sections are present in the AWT example documentation (Blue Streak of Death) and/or last year's Spinlayden doc but are **completely missing** from the current `main.md`.

1. ~~**Team Biographies** — Individual bios for each team member (example doc had a paragraph + photo per person). Required for scoring under "member attribution."~~ — Added Team Biographies section to `main.md` after Our Partners. Tom Kramer's bio added; remaining team bios pending submission.
2. ~~**Mentor / Advisor Biographies** — Bios for Jack Carbone, Adam Carbone, and JT Mackey. Example doc had detailed bios with photos.~~ — Added Mentor / Advisor Biographies section placeholder to `main.md`. Awaiting bios from advisors.
3. ~~**Acknowledgements** — A section thanking sponsors, mentors, school administration, etc.~~ — Added Acknowledgements section placeholder to `main.md`. Content pending.
4. **CAD Models** — Screenshots/renders of the Fusion 360 model showing the full assembly and individual components. Example doc had multiple views and exploded diagrams.
5. ~~**Risk Analysis** — Identify risks to the project (schedule, manufacturing, competition) with mitigation strategies. Example doc had a full risk matrix.~~ — Done. main.md `### Risk Analysis` (around L716) has Table 11 *Project-Level Risk Matrix* with 8 risks grouped as Schedule (documentation deadline, testing window), Manufacturing (machining access loss, 3D-print failure under combat loads, parts shipping delay), and Competition (exposed wheels, operator control errors, battery depletion). Each row has Cause, Impact, Severity (1-10), Likelihood (1-10), and Mitigation. Component-level risks are covered separately by the FMEA (Table 10, *Structural Analysis*).
6. ~~**Manufacturing Plan** — Detailed step-by-step manufacturing procedures (not just the current placeholder). Example doc described each fabrication step with photos.~~ — Rewrote the Manufacturing placeholder under Project Overview with a real overview pointing to the detailed Fabrication section (CNC mill, waterjet, 3D print). Fabrication section already contains the step-by-step procedures per process.
7. ~~**Material Selection** — Justification for why 6061 aluminum and A516 carbon steel were chosen. Compare alternatives considered.~~ — Added full material selection section with justifications and alternatives for 6061 aluminum, A516 carbon steel, 1045 carbon steel, and 3D printing materials
8. ~~**Accounting / Budget** — A budget table or spreadsheet showing costs for materials, parts, registration, etc. Example doc had a detailed budget breakdown.~~ — Added full parts list and budget summary from Excel spreadsheet
9. ~~**Time Management** — A Gantt chart or detailed timeline showing planned vs. actual progress across the season.~~ — Added Time Management subsection to `## Team Meltdown - Tasks Distribution` with Table 6c (Season Timeline — Planned vs. Actual) covering 13 phases from Introduction through Competition.
10. **Bill of Materials (BOM)** — Complete parts list with part numbers, quantities, suppliers, and costs. Different from the missing "parts list" in Material Management.
11. **Data Management** — How the team manages files, CAD versions, documentation drafts, etc.
12. ~~**Action Plan** — A structured plan showing what needs to happen, who's responsible, and by when.~~ — Added Action Plan subsection to `## Team Meltdown - Tasks Distribution` with Table 6b mapping 11 work areas to leads, supporting members, and deadlines.
13. ~~**Inventory** — List of all tools, equipment, and materials the team has access to.~~ — Added inventory table under Team Procedures with tools (DeWalt drill/impact, Ryobi drill, hex keys, pliers, bits, wrenches) and equipment
14. **Configuration** — Detailed bot configuration: electronics layout, component placement, wiring routing. Last year's doc had a Configuration section.
15. ~~**Positive / Negative Influence Tables** — Example doc had structured tables analyzing what worked and what didn't from influence bots (not just a paragraph).~~ — Added Positive/Negative table and detailed Negative Aspects — Problems and Solutions table to Influences section
16. ~~**Problem / Solution Analysis** — Example doc broke down specific design problems and how they were solved.~~ — Covered by the Negative Aspects — Problems and Solutions table in Influences section (7 items with detailed Problem/Solution columns)
17. ~~**Interview Preparation** — Not a doc section, but the team needs to prepare for the 15-minute judge interview. All members should be able to speak to the design, manufacturing, and team process.~~ — Created `interviewPrep.md` with all 8 scored questions, suggested talking points, delivery tips, and quick reference card. TODOs added inside the file for items needing team input.

---

## main.md - Placeholders / TODOs

18. ~~**Line 39** - `**2026 Design:**` — Empty, no content after it~~ — Filled in at main.md line 67 with a two-sentence design summary (15-lb hexagonal meltybrain full-body spinner, 6061 aluminum chassis + A516 blades, dual BaneBots P61 gearboxes @ 645.6 RPM, plus the 1.0→2.0 improvements). Synthesized from existing Bot Description / Key Stats / Material Selection content; design team can revise with their own wording if desired.
19. ~~**Line 122-124** - `## WEIIII - Riverside Robotics` — Entire section is just "TODO: Placeholder for formatting reasons." What is WEIIII?~~ — Replaced with Team Biographies, Mentor / Advisor Biographies, and Acknowledgements sections
20. ~~**Line 130** - Design section TODO about talking to Adam about the table from example doc pages 14-15~~ — Replaced with a proper Design section intro paragraph describing the iterate-not-reinvent philosophy and previewing the Previous Bot / Strengths-Weaknesses / 2026 Design subsections below it.
21. **Line 134** - `**Previous Bot:**` — Label with nothing after it (no image or description)
22. ~~**Line 138** - Influences section trails off with "We also hopefully improved on..." then a TODO~~ — Replaced with full intro paragraph and two influence tables
23. ~~**Line 175** - Manufacturing section is just a placeholder~~ — Replaced with a three-process overview (CNC milling, waterjet, FDM 3D printing) that points readers to the detailed Fabrication section for step-by-step procedures.
24. ~~**Line 288** - Material Management says "Listed below is our parts list" but there's no list — just a TODO~~ — Added parts list and budget from Excel spreadsheet
25. **Line 427** - Overview section is a TODO
26. **Line 429** - `**Stats:** It spins fast, probably` — Clearly a joke placeholder
27. ~~**Lines 504-534** - Seven consecutive TODO stubs~~ — Filled in Refinement (8 improvements from 1.0→2.0), Structural Analysis (FMEA table with 8 failure modes), Weapon System Details (blades, energy output, full-body spinner), Drive System Details (motors, ESCs, gearboxes, wheels, belts), Power System Details (batteries, kill switches, power distribution), Wiring Schematic (power + control + BEC paths), Testing Results (4 testing phases). **Still TODO:** Engineering Drawing Set (awaiting CAD team exports), wiring diagram image, full-speed testing results update
28. **Line 502** - Closing Remarks is a TODO

---

## main.md - Weird / Questionable Info

29. ~~**Line 246** - Alexander Holmes's role is listed as **"I have not see him work"** — probably shouldn't be in a final doc~~ — Fixed, now shows "Mechanical | Marketing"
30. ~~**Line 261** - Kaydan Kerr has **no role listed** (blank cell)~~ Added Documentation and Mechanical because of missing info 
31. ~~**Line 265** - Kasey Kurzinger is listed as "Advisor" but is in **8th grade**~~ — is that right? Removed Advisor and added Documentation and Mechanical to becuause of missing information
32. ~~**Lines 345-353** - Key Stats in the Design Process section is a **duplicate** of the Key Stats table already in the Design section (lines 142-152) — same exact data in two places~~
33. ~~**Line 37** - Says team "expanded to 26 students" but line 96 says "approximately 30 students" — inconsistent count~~ — Fixed. All mentions of Team Meltdown headcount now read 19 students (the actual HS roster). Removed references to a second HS team (Team Stark / Jarvis); middle school JuniorBots teams retained.
34. ~~**Line 187** - Objective table says "Writing a robust Python script" but the Feb 3rd meeting note says the software was **rerolled in C#** — contradicts~~ — Fixed, now says "Writing a C# program"
35. ~~**Lines 383, 387** - Fabrication methods only lists CNC Milling and 3D Printing with no details~~ — Expanded with Waterjet Cutting, CNC Milling, and 3D Printing details

---

## meetingNotes.md - Missing Notes

36. ~~**Line 305** - February 3rd Meeting: **Notes field is empty**~~ — Notes have been filled in
37. ~~**Line 395** - March 10th Meeting: **Notes field is empty**~~ — Notes have been filled in
38. **Line 414** - March 17th Meeting: **Notes field is empty**
39. **Line 433** - March 31st Meeting: **Notes field is empty**
40. **Line 450** - April 3rd Meeting: **Notes field is empty**
41. **Line 472** - April 7th Meeting: **Notes field is empty**
42. **Line 491** - April 11th Meeting: **Notes field is empty**

---

## meetingNotes.md - Weird Info

43. ~~**Lines 403-404** - March 10th: A full paragraph explanation is crammed into a Tasks and Goals table cell — reads more like a note than a task~~ — Moved explanation into Notes field, cleaned up table rows
44. ~~**Line 313** - Feb 3rd: "Rerolled Software in C#" — significant pivot from Python with no explanation in the notes (notes are blank)~~ — Notes now filled with explanation of the C# pivot
45. ~~**Line 377** - March 3rd: "All productivity went out the window once Dominos arrived" — funny but might want to rephrase for a formal doc~~ — Dominos reference removed

---

## Nice-to-Have Follow-ups

46. **Re-photograph assembled chassis with aluminum walls** — Figures 16 and 16b currently show the wiring-integration build with 3D-printed PLA placeholder walls (used while waiting on the CNC-milled aluminum walls). Once the aluminum walls return from the CNC shop and are installed, take a matching set of photos and swap them into the Physical Assembly subsection. Not required for the April 18 submission — the current photos are correctly captioned as a placeholder-wall wiring mockup.

---

## Scoring Reminders (from AWT Documentation Details)

- **Professional Presentation** — Clean formatting, consistent style, no placeholder text or jokes
- **Rubric Compliance** — Every section the rubric asks for must exist and have real content
- **Supporting Documents** — Spreadsheets, drawings, specs, budgets should be included or referenced
- **Technical Terminology** — Use proper engineering terms throughout
- **Clear Labeling** — All figures, tables, and diagrams need captions/labels
- **Original Writing** — No copy-paste from external sources without attribution
- **Team Member Attribution** — Credit who did what throughout the document

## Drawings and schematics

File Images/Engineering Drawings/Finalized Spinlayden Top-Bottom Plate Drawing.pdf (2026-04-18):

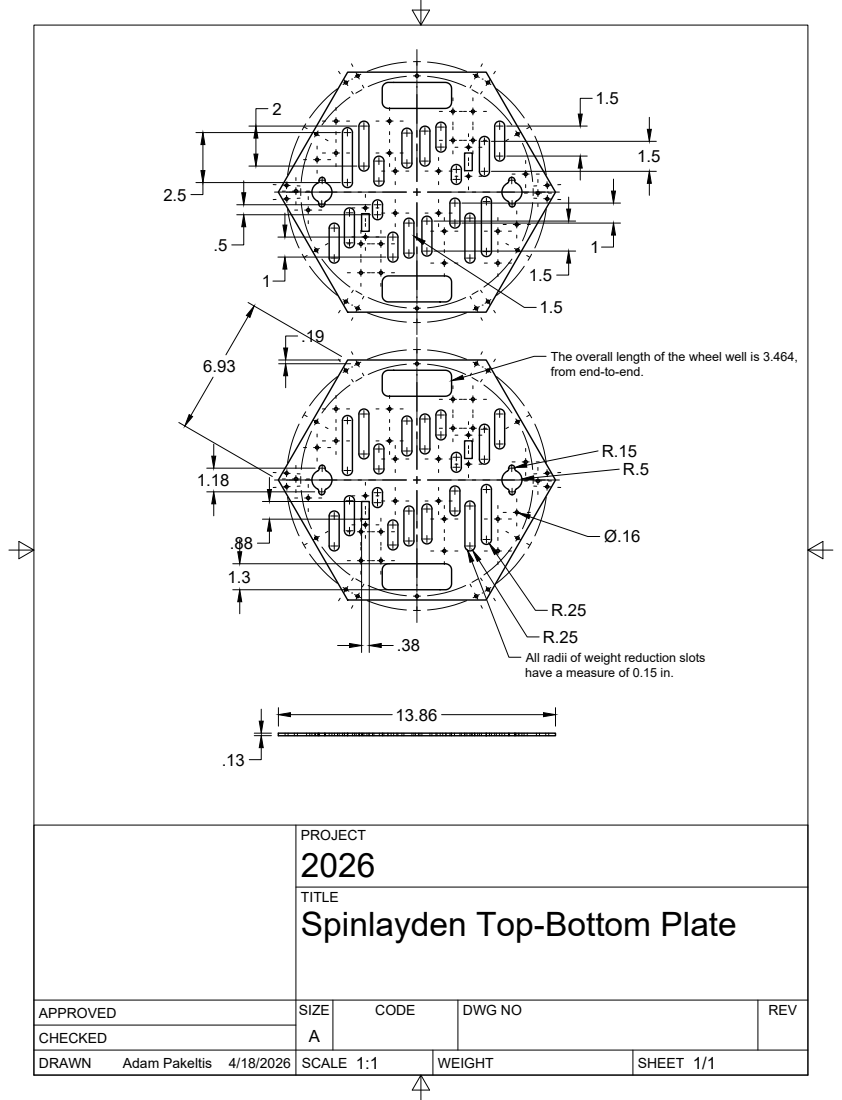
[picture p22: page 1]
SIZE; CODE; DWG NO; REV; Adam Pakeltis

The overall length of the wheel well is 3.464,
from end-to-end.

All radii of weight reduction slots
have a measure of 0.15 in.

PROJECT
Spinlayden Top-Bottom Plate

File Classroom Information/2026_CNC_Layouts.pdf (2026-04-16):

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

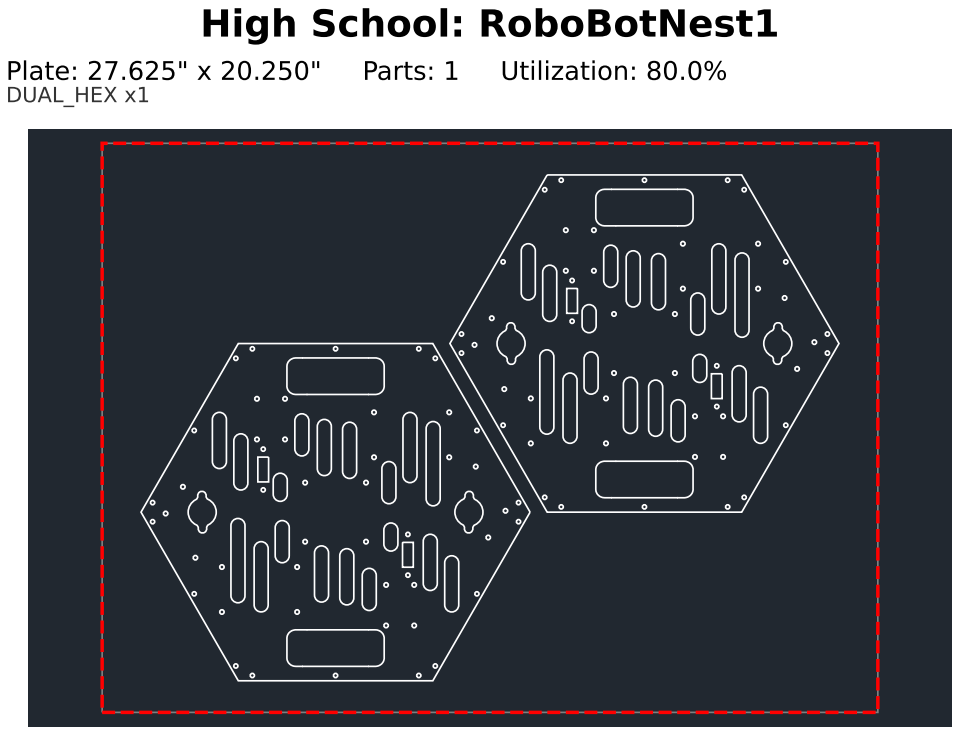
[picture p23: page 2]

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

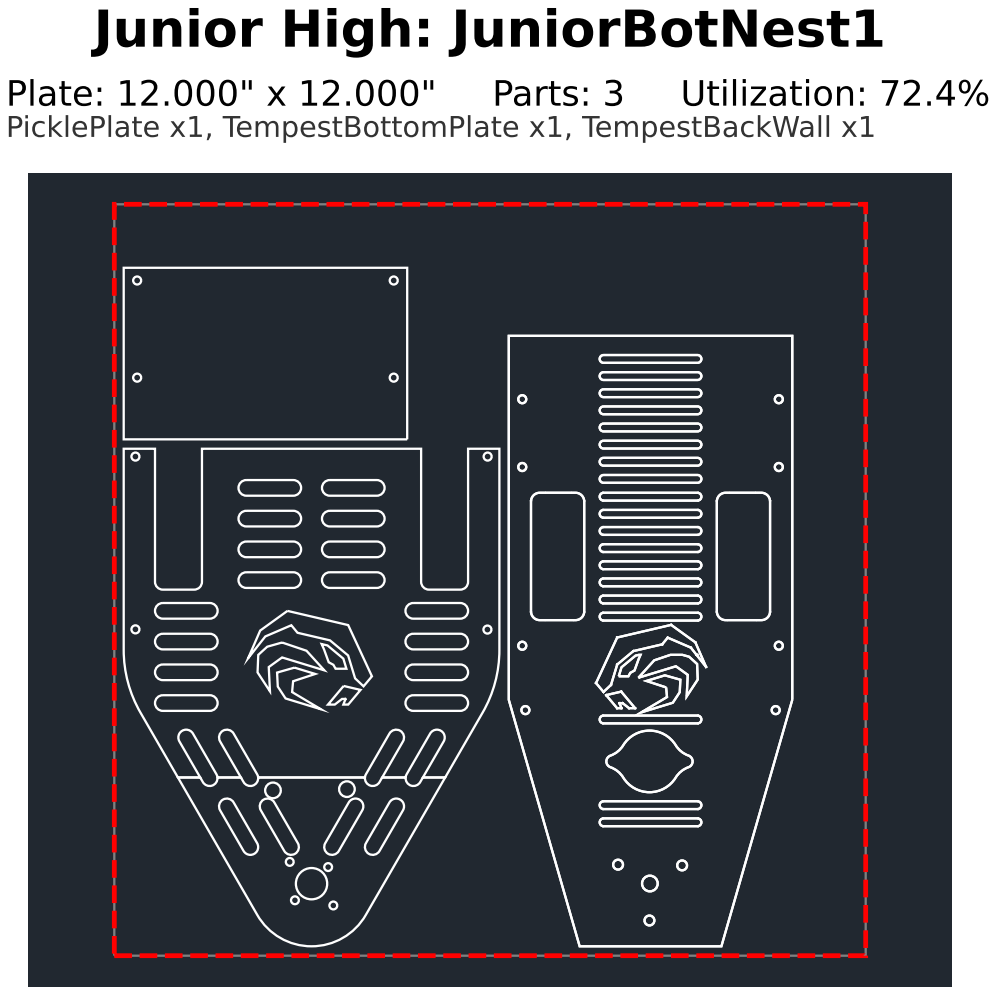
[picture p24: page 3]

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

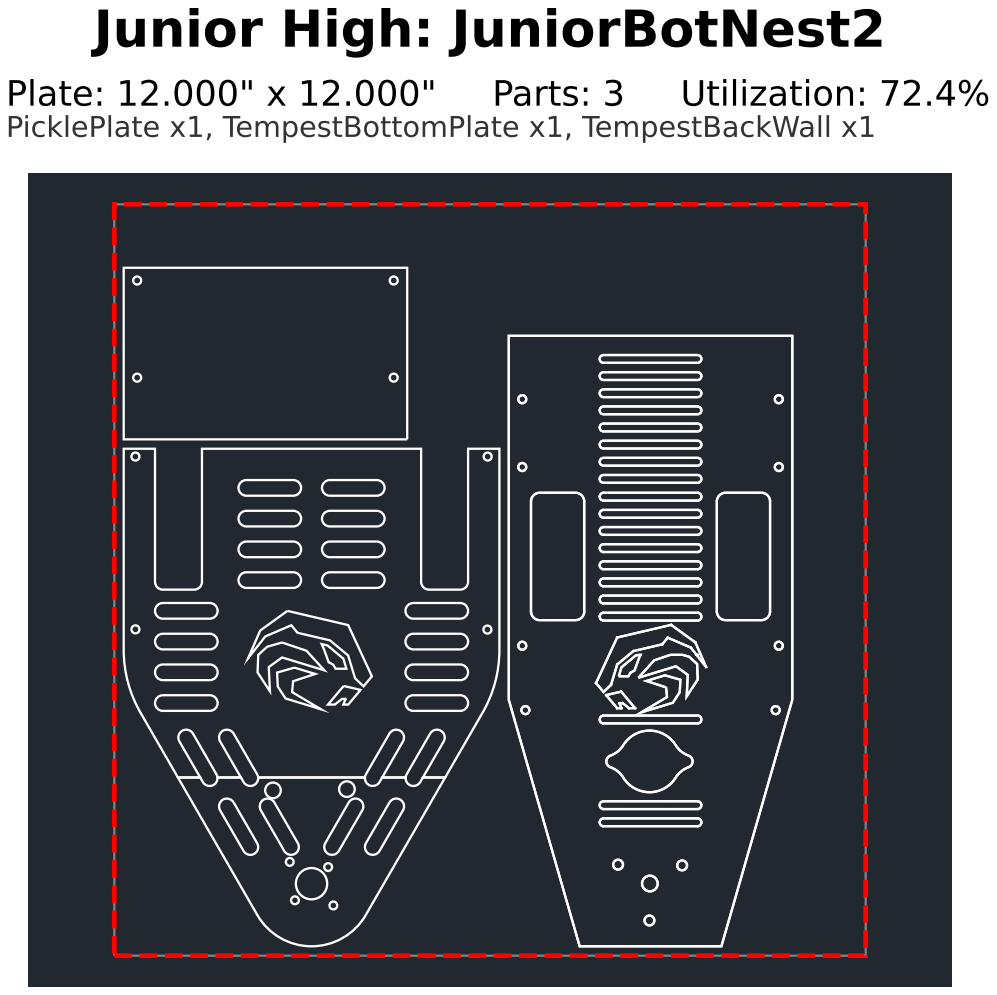
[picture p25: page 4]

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

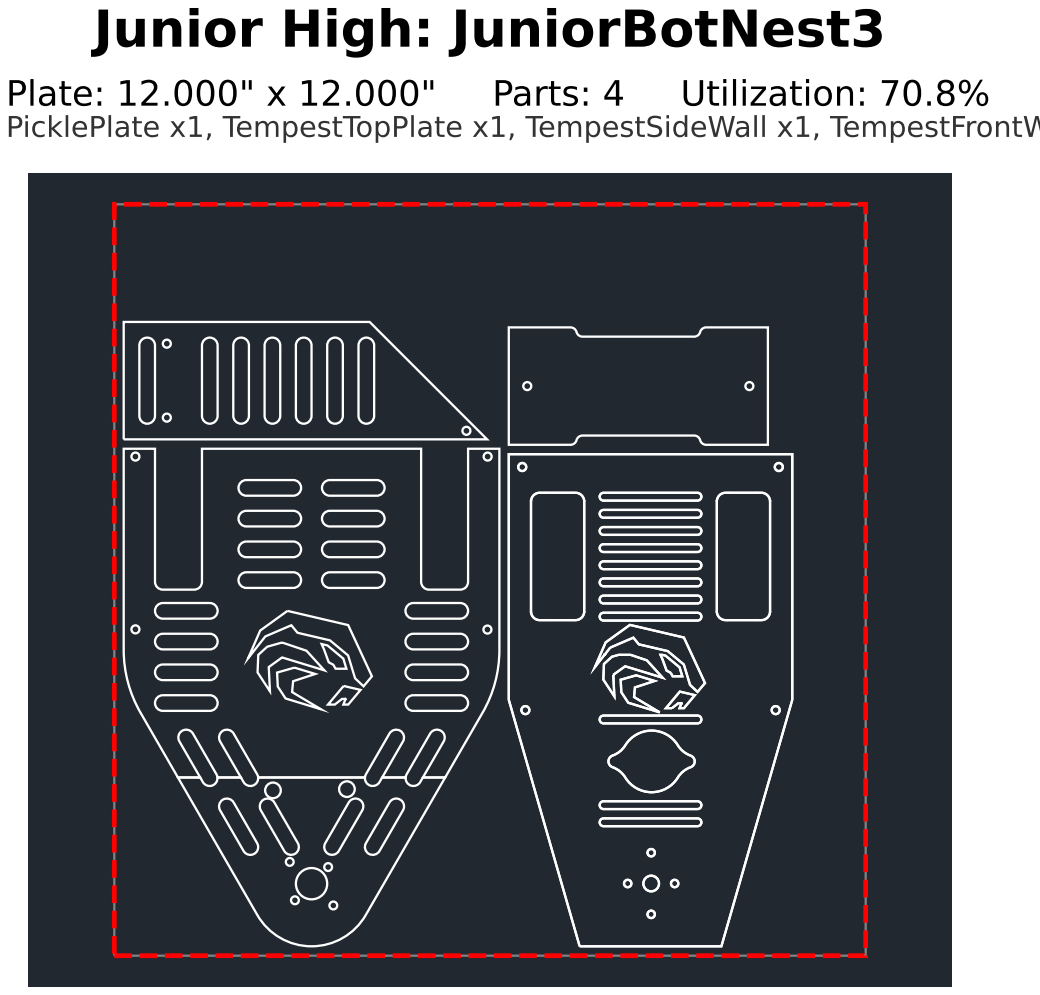
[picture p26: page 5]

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

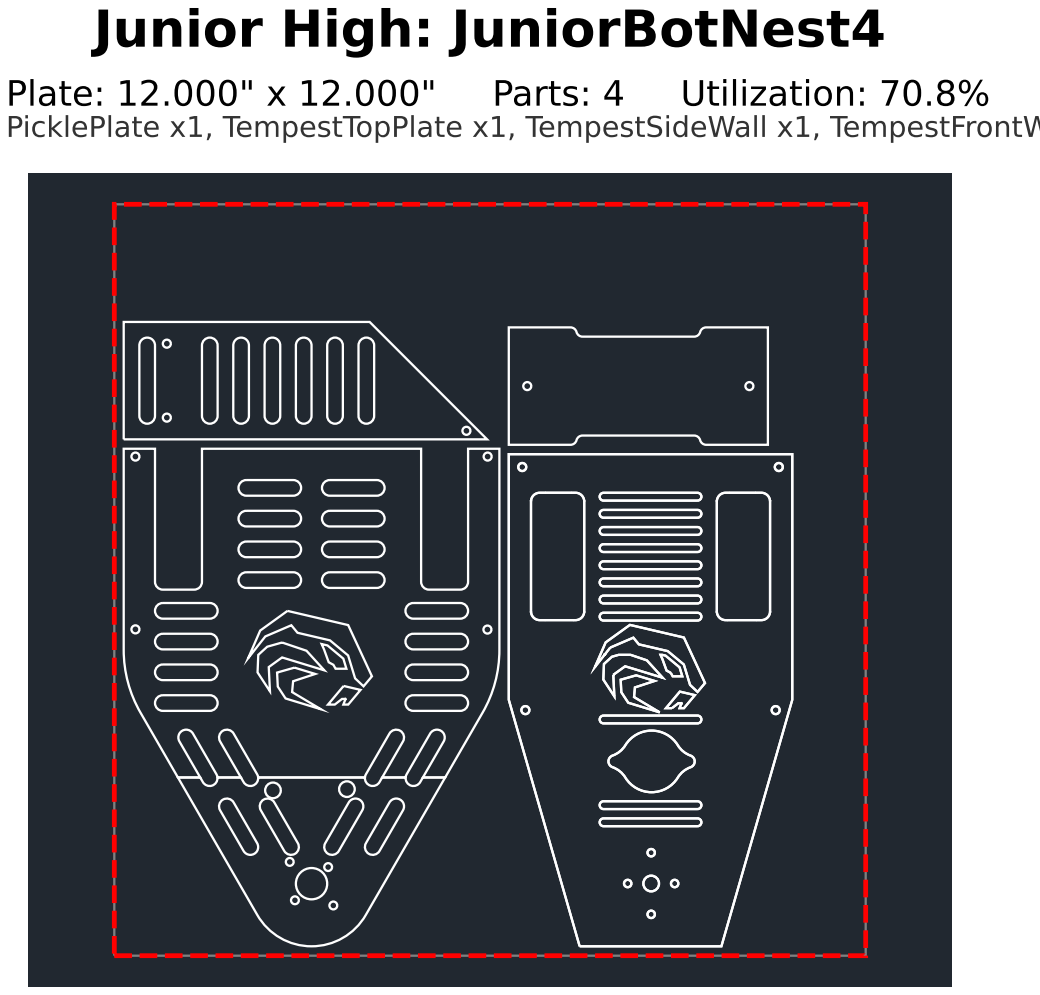
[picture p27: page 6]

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

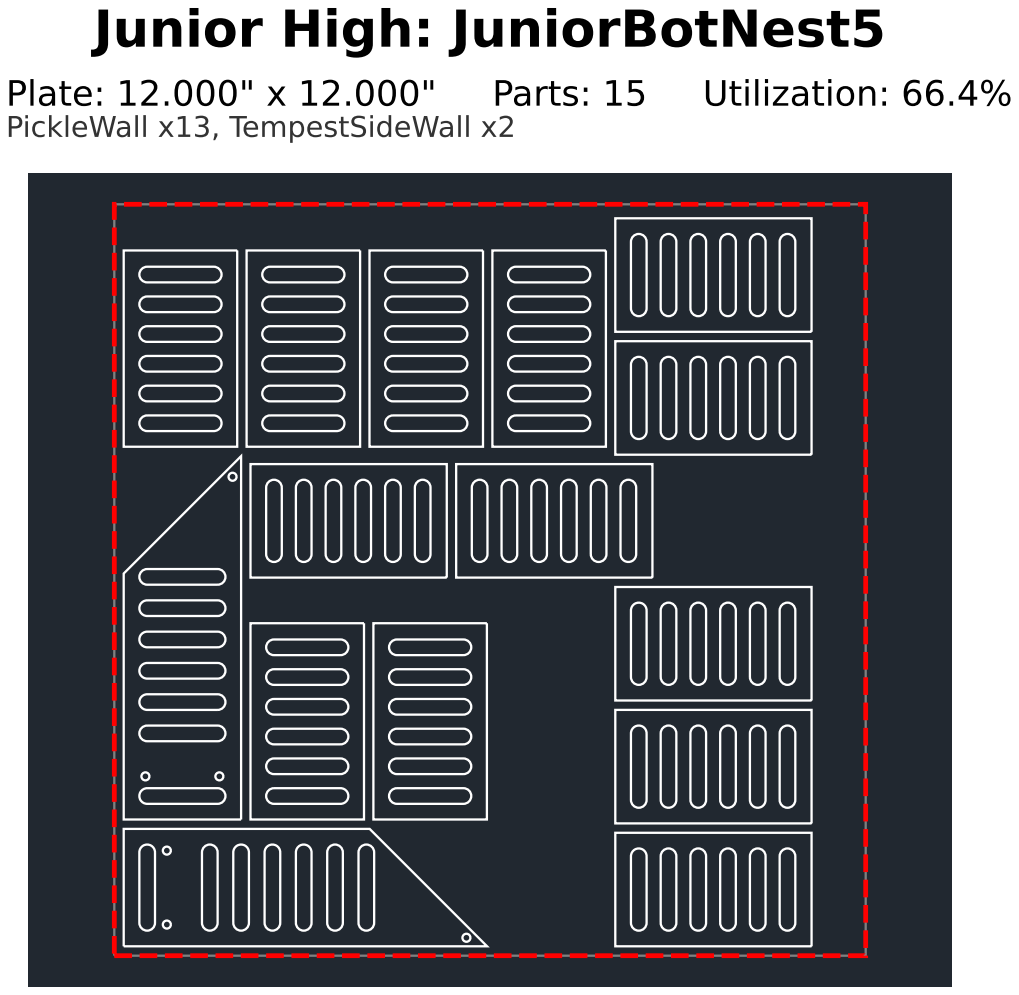
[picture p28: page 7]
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

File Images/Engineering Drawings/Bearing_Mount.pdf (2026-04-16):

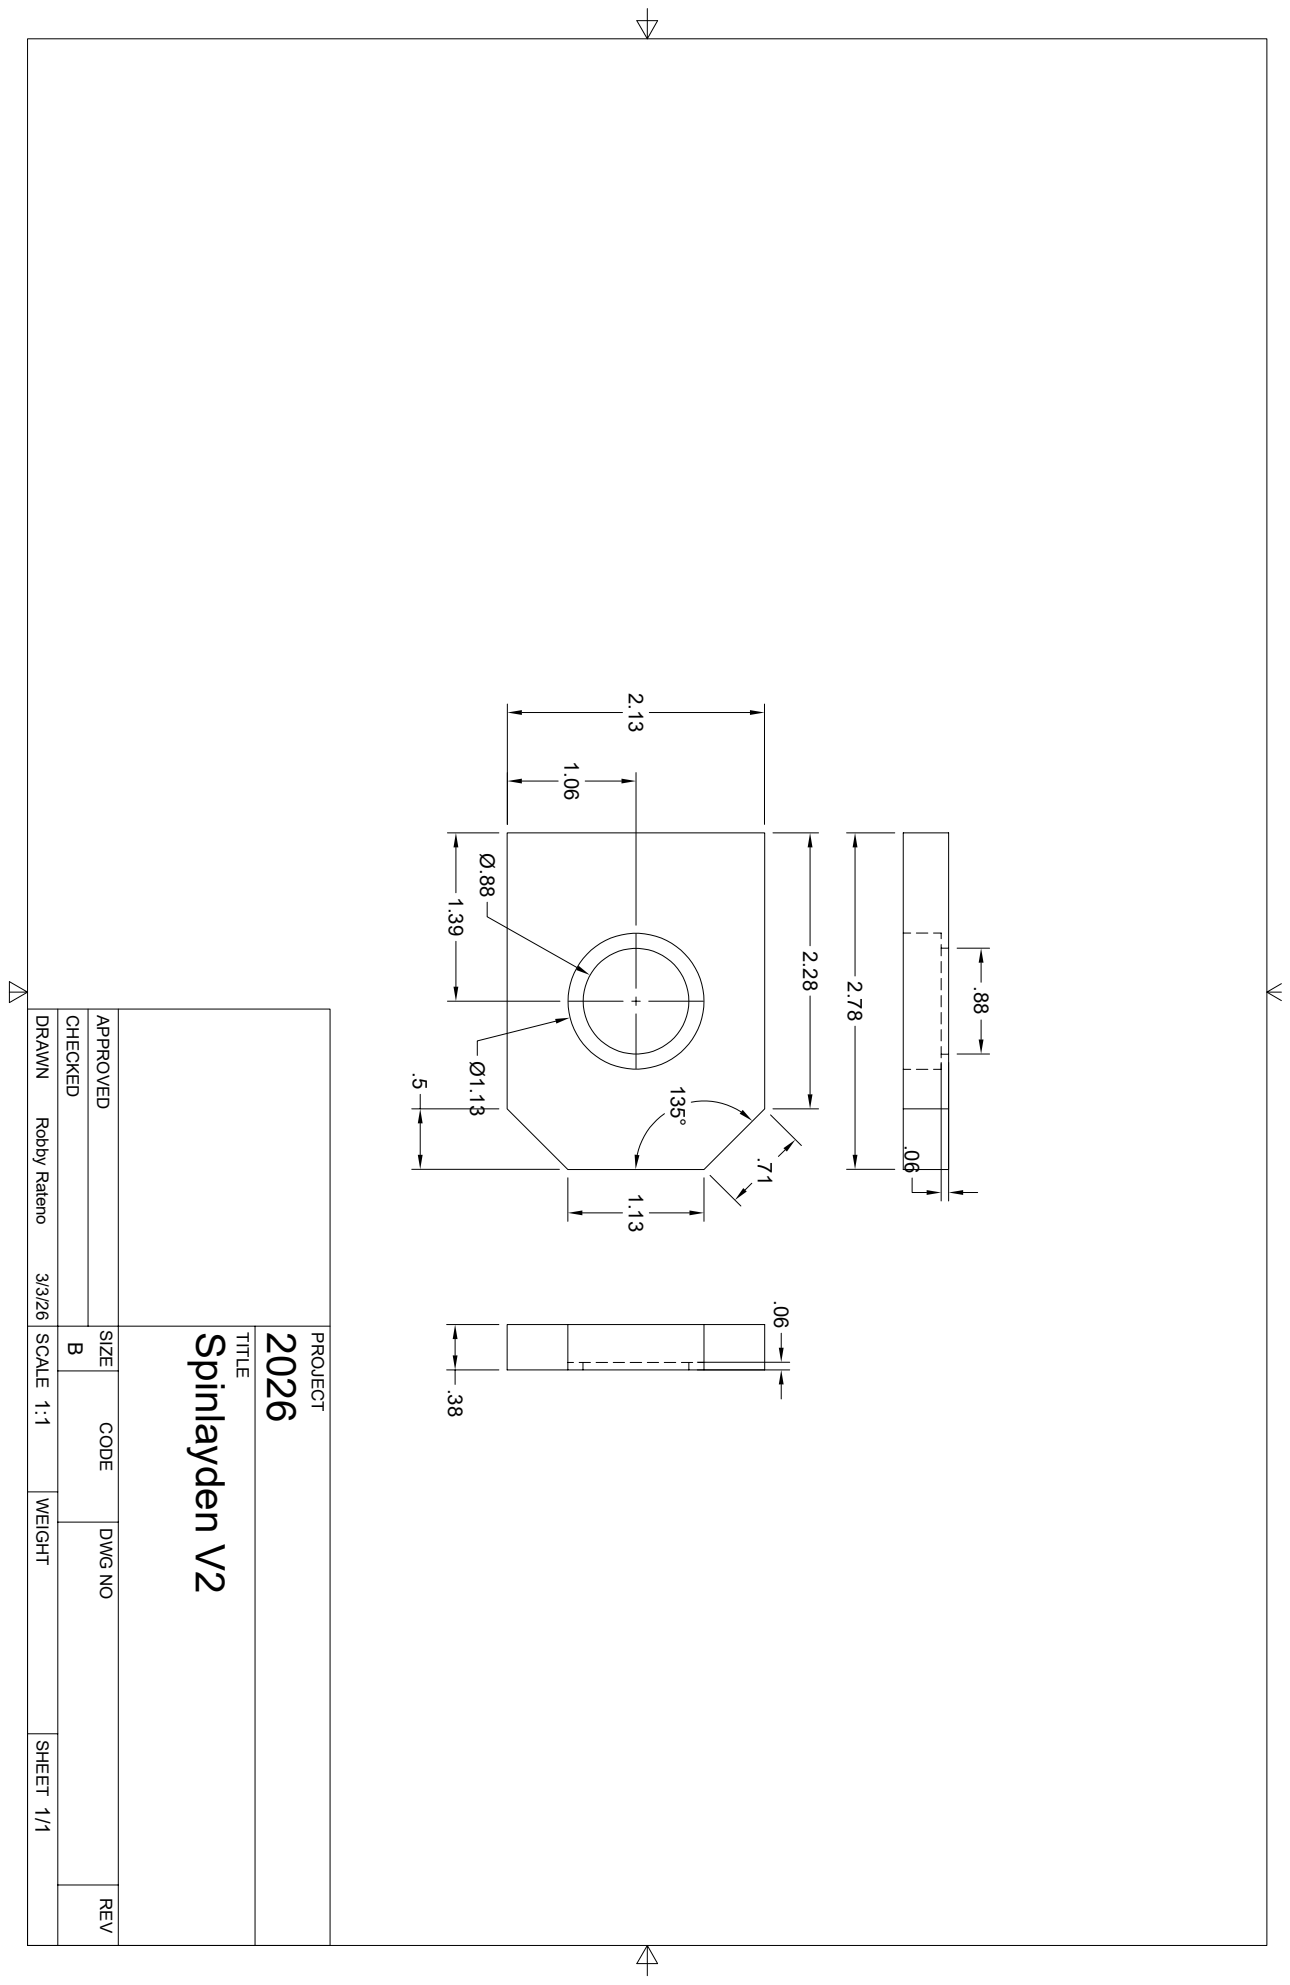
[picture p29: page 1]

TITLE PROJECT DRAWN CHECKED APPROVED SCALE WEIGHT SHEET DWG NO REV CODE SIZE 1/1 1:1 3/3/26 Robby Rateno BSpinlayden V2 2026 2.13 2.78 .38 Ø.881.39 1.06 135° 2.28 .71 1.13 .5 Ø1.13 .06 .88 .06

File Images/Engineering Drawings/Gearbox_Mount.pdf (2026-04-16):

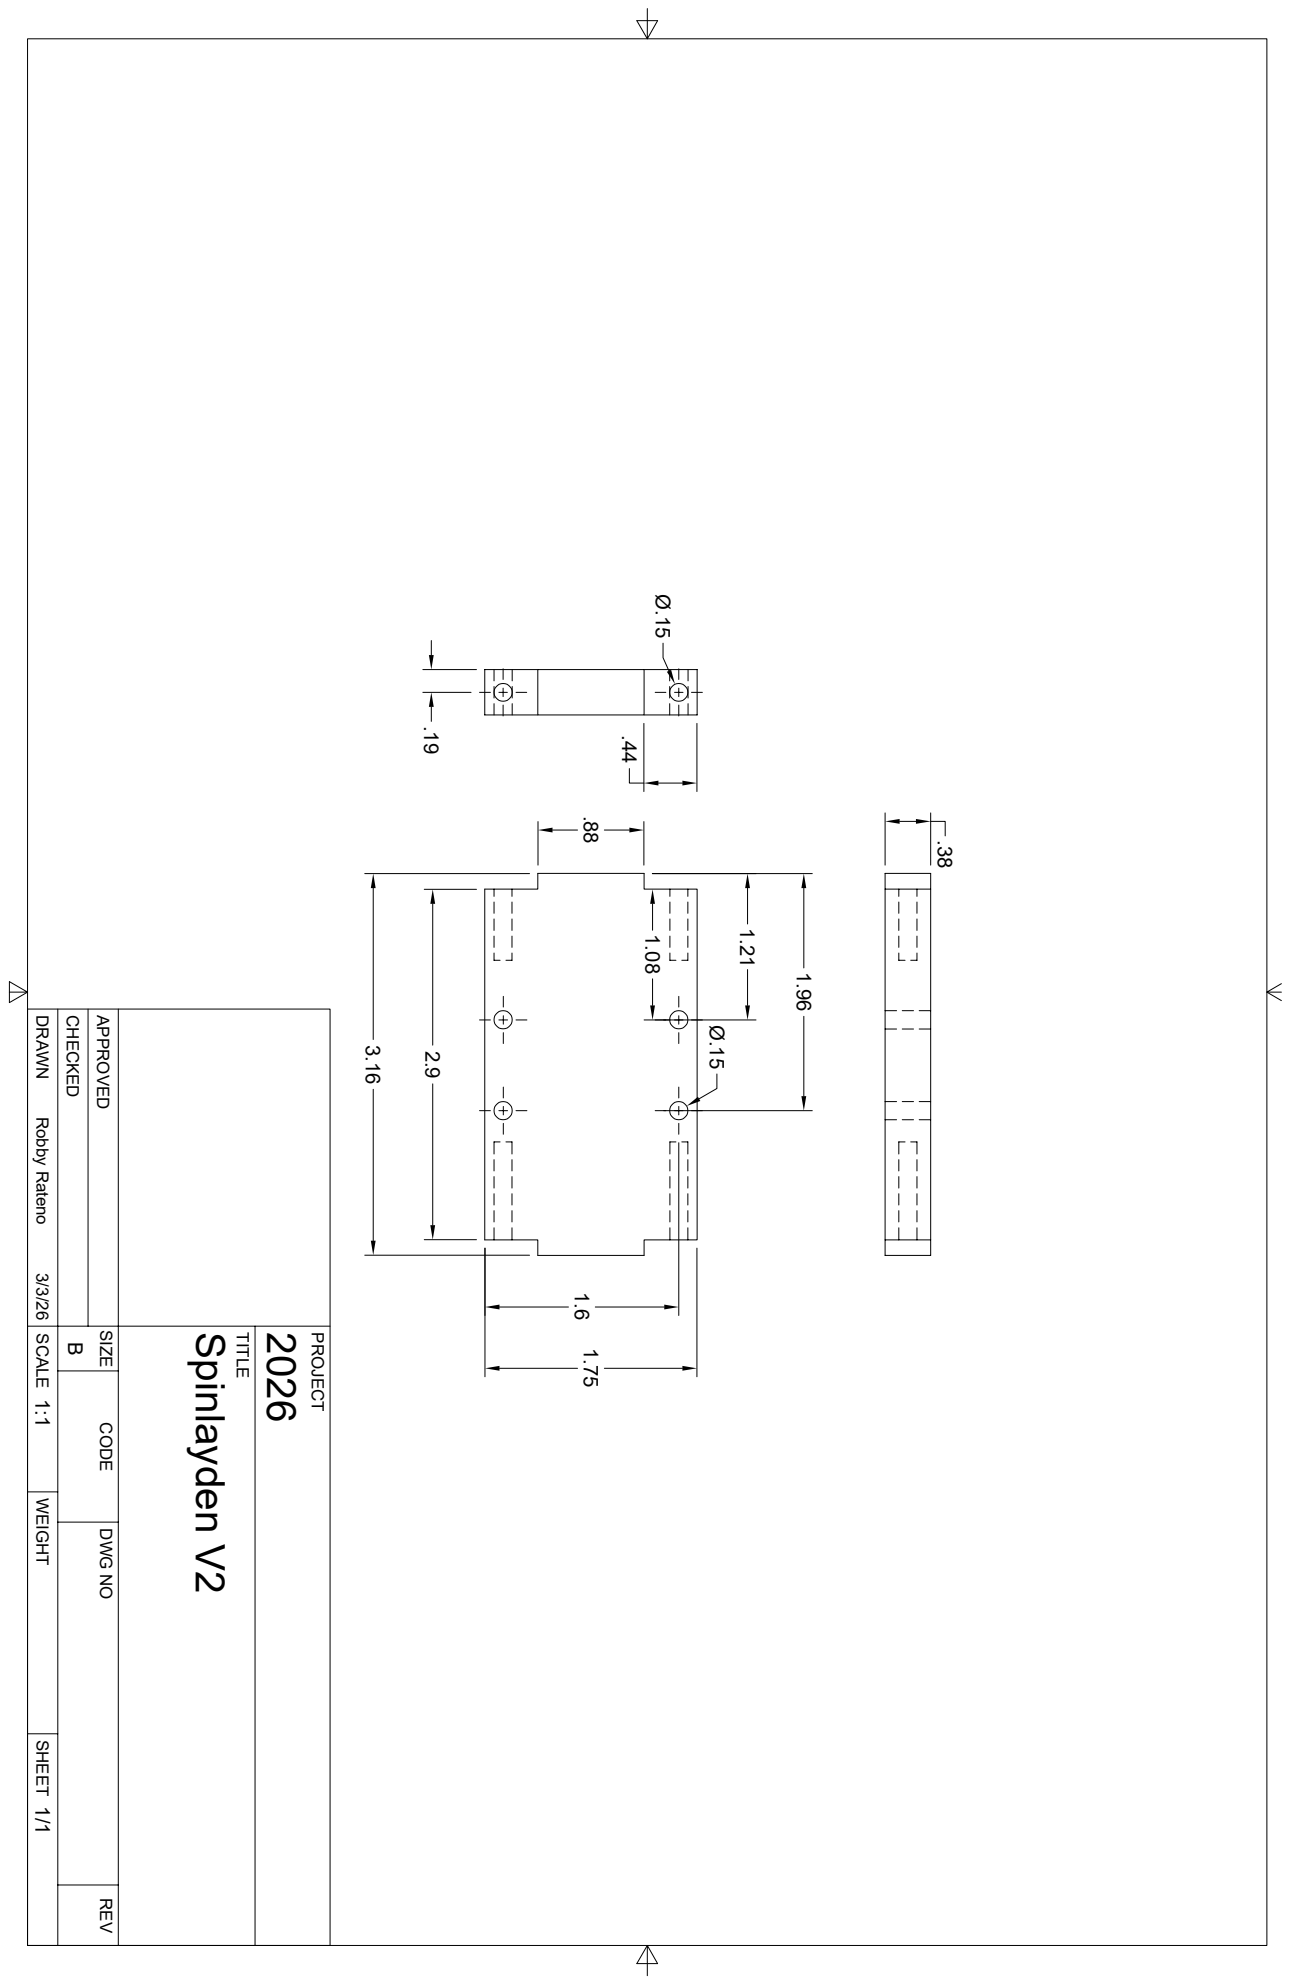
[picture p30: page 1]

TITLE PROJECT DRAWN CHECKED APPROVED SCALE WEIGHT SHEET DWG NO REV CODE SIZE 1/1 1:1 3/3/26 Robby Rateno BSpinlayden V2 2026 3.16 1.75 .38 Ø.15 Ø.15 1.96 1.6 1.21 .19 2.9 1.08 .88 .44

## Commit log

2026-04-14 Given stuff now on repo
    [Documentation Scoring 2026 (10-20-2025).xlsx, Interview Score Sheet.xlsx]
2026-04-15 Uploaded the Spredsheet and fixed 8.
    [Spinlayden 2026 Parts .xlsx]
2026-04-16 Hope I fixed the git issue
    [Bearing Holder.step, GearBox Mount.step, Wall.step]
2026-04-17 Claude made a cover page. It also fixed an error where I lost trace of the number of highschool students accros this documentation and standardiced that! (I know that is not how you spell that) <3
2026-04-17 Correct weapon system, rebuild budget, add 8 bios, write Design intro and Manufacturing sections
    - Weapon system: replaced A516 blade references with 1/2" carbon steel hex bolts
    (Everbilt SKU 800980) throughout all 2.0 sections; 1.0 history preserved
    - Bill of Materials + budget summary rebuilt from actual invoices: Monode aluminum
    donations zeroed, Custom Ink shirts ($965.25, students paid $15 flat), Everbilt
    hex bolts, Riverside HS PO 219831 reconciled
    - Removed AWT grant language from Acknowledgements and funding summary
    - Added 8 missing student bios: Dustin Hance, Jayden Craig, Kasey Kurzinger,
    Kaydan Kerr, Lukas Dauksa, Mher Poghosyan, Richard Rowland, Vincent Riha
    (all 19 bi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
2026-04-18 Add 4-18-26 doc-fix action list + three independent grader reports
    Grades converged on ~B (79/92, 72/96, 85/112). Five unanimous gaps
    captured in docFixes_4-18-26.md: Testing Results, Promotional/
    Fundraising, Manufacturing Plans, Meeting Minutes in main.md, and
    Wiring Schematic. Plus ASME drawing cleanup notes.
2026-04-18 Move build process into main.md Fabrication section
    Adds an Assembly Process subsection under Team Procedures > Fabrication
    and removes the standalone buildProcess.md.
2026-04-18 Fix rendering issues in main.md
    - Remove duplicate cover block that duplicated page-1 header content
    (redundant "Spinlayden Riverside Robotics" heading and team list)
    - Correct 4 broken image paths so figures render in the PDF:
    - Spinlayden 1.0 isometric render → Images/Last Year/
    - OMAX 5555 waterjet controller screenshot → Images/Discord/
    - Waterjet-cut chassis plates photo → Images/Discord/
    - WT901 IMU module photo → Images/Discord/
2026-04-18 Add full wiring schematic and PDF formatting reference
    - main.md: rewrite Power System and Wiring Schematic sections to match
    the actual build — 4x 3S Li-ion 3200mAh packs (2 parallel-spliced per
    motor), and a complete pin-by-pin signal table integrating the Pi 4
    GPIO wiring from the spinlayden control-software repo
    (FS-iA6B receiver on UART3, WT901/WT61P IMU on UART0, PWM0/PWM1 to
    both ESCs, Left ESC BEC powering the Pi)
    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
